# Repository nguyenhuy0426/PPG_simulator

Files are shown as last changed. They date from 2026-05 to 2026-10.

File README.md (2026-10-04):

# 🫀 PPG Signal Simulator — Raspberry Pi 4

**Dual-channel PPG research simulator with Raspberry Pi software, three KiCad 10 boards and a printable optical enclosure.**






**Group #2:** HuyNN, VyPT
**Institution:** Industrial University of Ho Chi Minh City (IUH) — Faculty of Electronic Technology
**Version:** 5.0.0 — waveform controls and timestamped recording

---

## 📋 Overview

The Raspberry Pi runtime synthesizes IR/RED signals at 100 Hz, interpolates them
for a nominal 500 Hz dual-MCP4725 output on ARM64, and acquires OPT101 signals separately.
`PPG_DAC_RATE_HZ` supports 100/200/500/1000 Hz; desktop default is 1000 Hz.
Pi GUI + BLE + A0 verification at 500 Hz completed 30 seconds without buffer
overruns or dropped samples. Optical waveform fidelity is still unverified.
The empirical SpO₂ mapping is configurable; a realistic plot does not establish
optical accuracy or compatibility with a particular pulse oximeter.

**Touch and sequence update (30 September 2026):** Numeric controls use sliders;
Settings and calibration include −/+ fine steps. **04 PPG morphology** offers
fitted Gaussian and an exploratory **LSM-GAN 30-second sequence**, a real training
reference, and a live **OPT101 RX** card (A0/A2). **A2 is disabled until its sensor is installed.**
Play/Stop uses the shared MCP4725 writer; clips stop at 30 seconds or when leaving
the page. Opening the page does not emit output. Classic Gaussian is preserved.

LSM keeps native 40 Hz timing and has no HR/notch conditioning. The existing v2
checkpoint has excessive beat variability relative to median validation data;
it is a development baseline, not a validated human-PPG replacement. IR/RED share
one shape with nominal scaling. See [architecture choice, measured sequence audit
and touch/output details](docs/ppg_touch_sequence_output_2026-09-30.md).
The [earlier morphology comparison](docs/ppg_morphology_selection_2026-09-28.md)
remains a historical exploratory result; test has already been viewed.

**RX beside TX & Bench Diagnostics (October 2026):**
- **Live A0/A2 RX card on every page:** Classic, Calibration, Recordings and PPG morphology each show a read-only RX card next to the TX plot (the earlier bottom dock, and the RX strip inside the Signal setup window, are removed). It displays the rolling 8-second window of raw ADC mV at up to 10 Hz refresh, with explicit status states (disabled, dry-run, stale, error, full-scale) and touch-optimized scrolling on 1024×600 screens ([docs/rx-monitor-2026-10-01.md](docs/rx-monitor-2026-10-01.md)).
- **Physical Sensor Diagnostic Protocol:** A bench test and signal conditioning plan is established for OPT101 / CJMCU-101 modules, covering internal 1 MΩ feedback verification, 3.3 V Grove Hat input limits, dark readings, stepped sine wave tests (1–10 Hz), and RC low-pass filtering at $f_c \approx 33.9\text{ Hz}$ ([docs/opt101-a0-diagnostic-2026-10-01.md](docs/opt101-a0-diagnostic-2026-10-01.md)).

| Live monitor | Waveform setup | 30-second sequence |
|---|---|---|
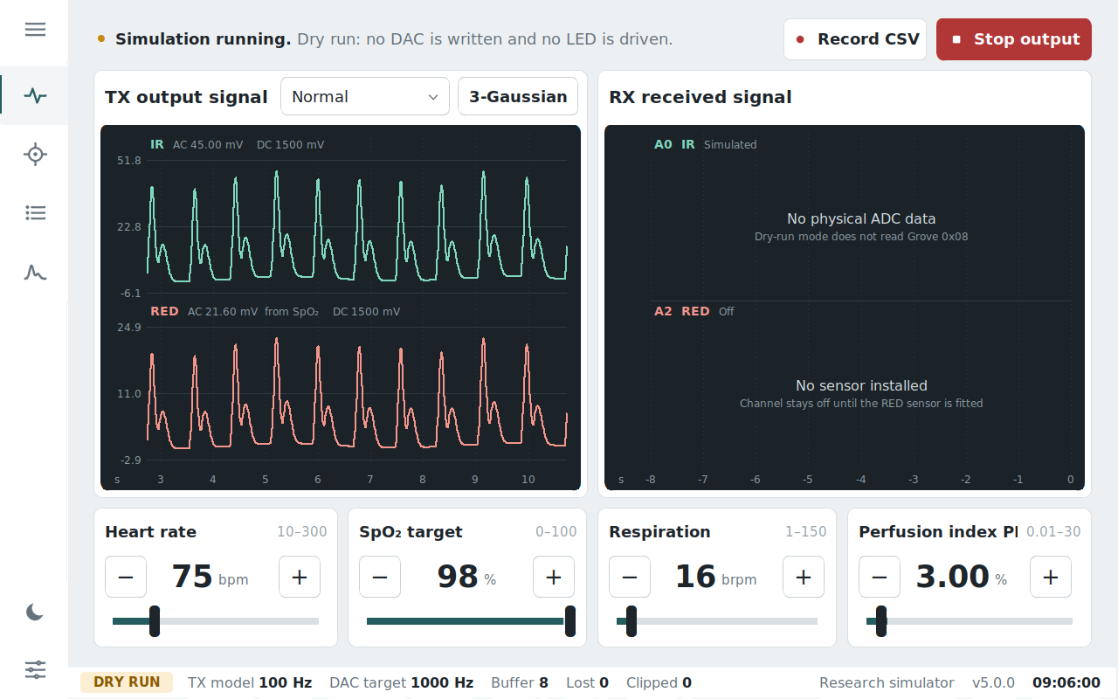
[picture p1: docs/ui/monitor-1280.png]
PPG monitor in dry-run mode
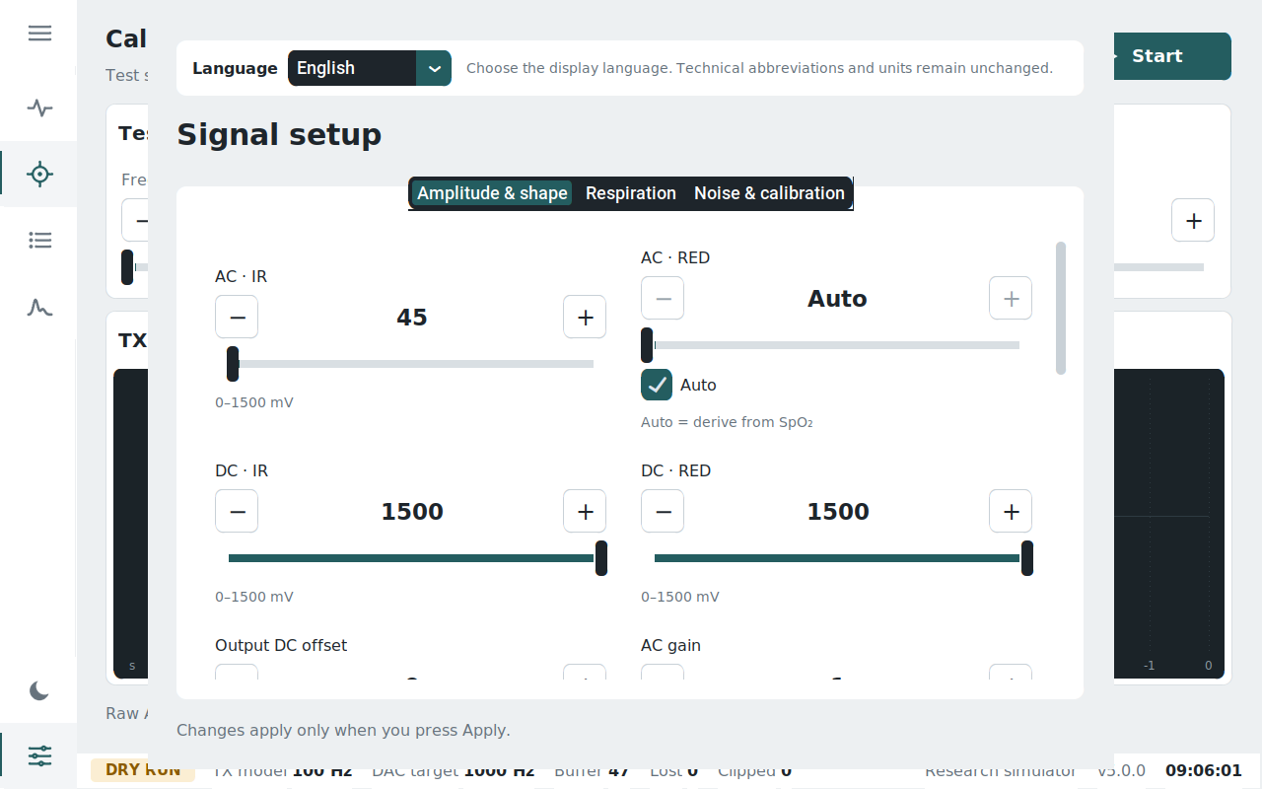
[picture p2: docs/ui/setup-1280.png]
Signal setup controls
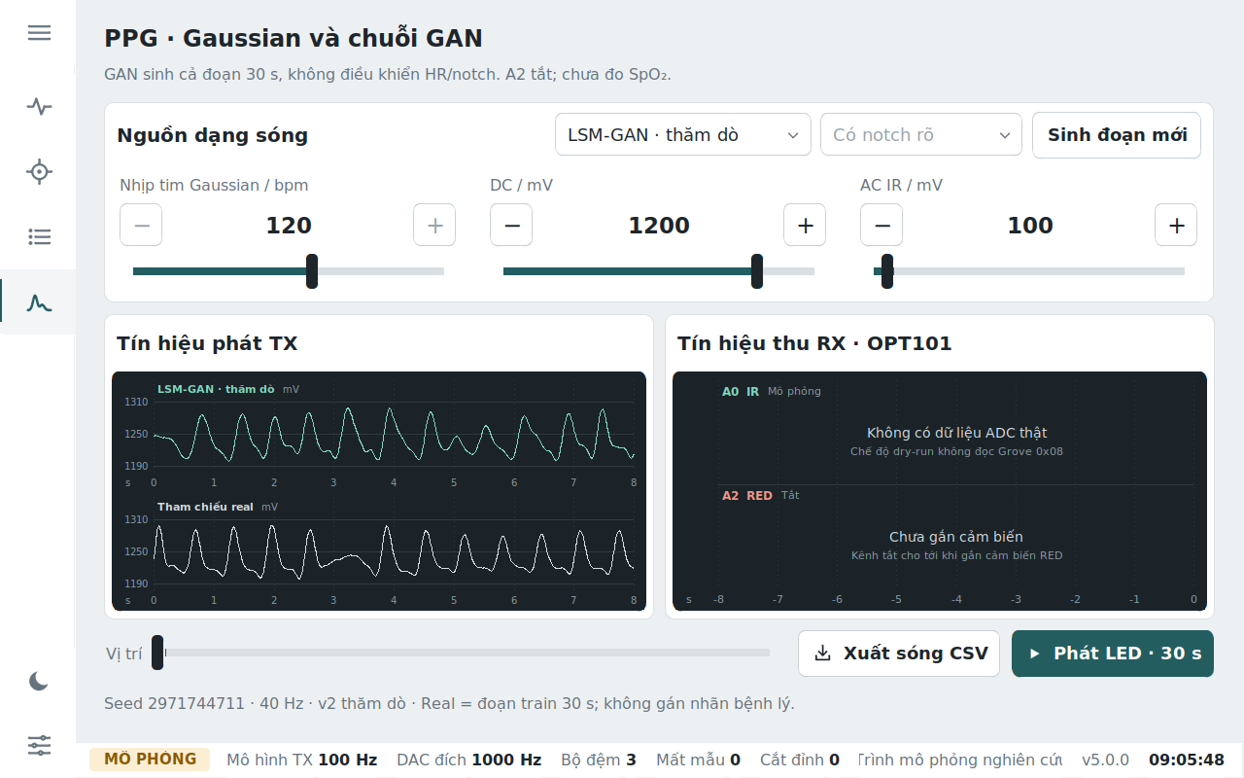
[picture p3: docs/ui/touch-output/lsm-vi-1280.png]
LSM-GAN sequence screen
|  |  |  |

### What's complete in v5

- Light controls, charcoal IR/RED plots, large setpoints and timestamp axes. The UI scales automatically from compact 7-inch 1024×600 panels through Full-HD/QHD desktop displays.
- HR 10–300 bpm; respiration 1–150 brpm; SpO₂ target 0–100%; PI convenience input 0.01–30%.
- Independent IR/RED AC and DC, AC/DC ownership, output offset, gain and polarity.
- PPG, sine, triangle and square waveforms; independent SP/DN/DP timing for each channel.
- Baseline, amplitude and frequency respiratory modulation, inhale/exhale ratio, per-channel variation and periodic apnea.
- Absolute-mV artefacts with optional seeds; configurable HR/amplitude, SpO₂/notch and beat-variability effects.
- Timestamped 100 Hz model-command CSV recording continues across pages; playback follows the recorded timestamps.
- Explicit Start/Stop for calibration; only the engine's DAC thread produces its sine output.
- Configuration round-trip, validation and atomic JSON save. Opening a page does not change signal parameters.
- English/Vietnamese UI; touch-sized controls; TX on the left and live OPT101 A0/A2 RX on the right of every page. A2 acquisition awaits an installed sensor.
- Collapsible left navigation rail (icons collapsed, labels overlay when expanded), light/dark theme saved in `config.json`, and a Classic page with TX and RX side by side. The status line reports *no MCP4725 at 0x60/0x61* instead of claiming LED output when the DACs do not answer.
- `scripts/deploy_and_run.sh` (run on the laptop): SSH check, `i2cdetect -y 1` report for 0x08/0x60/0x61, rsync to the Pi, restart the app on the Pi display, and a dry-run copy on the laptop. When the Ethernet link reports `NO-CARRIER`, use the Wi‑Fi address: `PI_HOST=user@<pi-wifi-ip> scripts/deploy_and_run.sh`, and stop any other running instance first so two apps do not share I2C/BLE.

See [the continuation and validation report](docs/phase_reports/V5_CONTINUATION_REPORT.md)
for scope, evidence, commercial-reference comparison and physical validation still needed.

### Neural waveform models

The current **04 PPG morphology** page keeps the original three-Gaussian
generator and offers the LSM-GAN sequence as an experimental model. The
cWGAN-GP checkpoint below is retained for research comparison; it is not the
current sequence source. Both neural models were trained from BIDMC 1.0.0 PPG
records using subject-separated train/validation/test groups. They do not learn
separate IR and RED optical channels.

| Model | What goes in → what comes out | Network idea | Current role |
|---|---|---|---|
| cWGAN-GP pilot | 32-value random latent vector + 7 measured morphology conditions → one 256-point, phase-normalized pulse | Dense layers followed by three linear-upsample/Conv1D stages; strided-convolution critic; Wasserstein loss with gradient penalty | Research artifact only; the pilot export contains G but not its trained critic. The app's older preview repeated this one pulse to form a longer trace. |
| LSM-GAN v2 | A random 1,200-point noise strip → 1,200 PPG samples, 30 s at 40 Hz | Generator has parallel Conv1D branches (kernels 5/21/61) and a spectral-matching objective; its discriminator is a CNN with two real/fake scores | Experimental long-sequence option in page 04; no HR/notch control. |

For LSM-GAN, training used 624 non-overlapping 30-second windows from 32
patients; validation and test each used 112 windows from 7 separate patients.
BIDMC's 125 Hz signals were resampled to 40 Hz, filtered at 0.9–5 Hz and
normalized per window. This is not raw, full-band PPG or a healthy-population
dataset. The model produces a normalized shape; the app maps that shape to
nominal IR/RED voltage levels, so it does not predict two independently learned
optical signals or calibrated SpO₂.

These experiments are **exploratory** because the test set had already been
viewed. cWGAN makes a single pulse while LSM-GAN makes a long sequence, so
their scores are not a fully like-for-like ranking. Selection considers the
pre-agreed spectrum similarity, autocorrelation and high-frequency energy;
loss and discriminator scores alone are not evidence of realistic PPG.
See the [detailed LSM/GAN report](docs/ppg_lsm_gan_report_2026-09-26.md),
[cWGAN and LSM integration audit](docs/ppg_neural_preview_report_2026-09-28.md)
and [current sequence and hardware validation](docs/ppg_touch_sequence_output_2026-09-30.md).

### Key Specifications

| Parameter | Value |
|---|---|
| Platform | Raspberry Pi 4 (Ubuntu 24.04/26.04 LTS, arm64)  |
| UI Library | CustomTkinter |
| DAC | MCP4725 (12-bit, I2C) × 2 — IR & Red channels |
| Model Rate | 100 Hz |
| DAC Rate | Pi: 500 Hz target; configurable; Linux/I²C timing requires measurement |
| Data Recording | 100 Hz model commands, timestamped CSV in `dataset/` |
| DAC Voltage Range | Configured 0–3.28 V (0 → 0, 3.28 V → 4095) |
| Live RX ADC Channels | A0 (IR) & A2 (Red) on Grove Base Hat (I2C 0x08) |

---

## 🛠️ Hardware Architecture

### Pin Mapping (Raspberry Pi 4, BCM numbering)

```
MCP4725 DACs (I2C Bus 1):
  GPIO2 (pin 3)   → I2C1_SDA
  GPIO3 (pin 5)   → I2C1_SCL
  Addresses: 0x60 (IR channel), 0x61 (Red channel)

Display:
  HDMI → Any screen (auto-detect resolution)
```

### Three KiCad 10 boards

The current CAD release has two alternative receiver boards and one LED
driver. Assemble **either** receiver for the optical channel pair; the V-cut
panel contains all three designs for fabrication, then separates into three
electrically independent boards.

| Board | Size | Main parts | Project |
|---|---:|---|---|
| OPT101 receiver | 70 × 20 mm | Two OPT101P in DIP-8 sockets; 2 mm Grove A2/RED and A0/IR headers; ADS1115 signal header; supply bypass and output RC | [Schematic, PCB and assembly notes](hardware/opt101_receiver_kicad/opt101_receiver/README.md) |
| BPW34 receiver | 70 × 20 mm | Two BPW34, two OPA333 TIAs, 1 MΩ/22 pF feedback, 2 mm Grove headers, ADS1115 signal/GND header | [Schematic, PCB and assembly notes](hardware/bpw34_receiver/README.md) |
| LED/IR driver | 70 × 40 mm | Two plug-in MCP4725 modules, socketed LM358, two 2N4401 current sinks, LED and 5 V headers | [Schematic, PCB and assembly notes](hardware/led_ir_driver/README.md) |

| OPT101 receiver | BPW34 receiver | LED/IR driver |
|---|---|---|
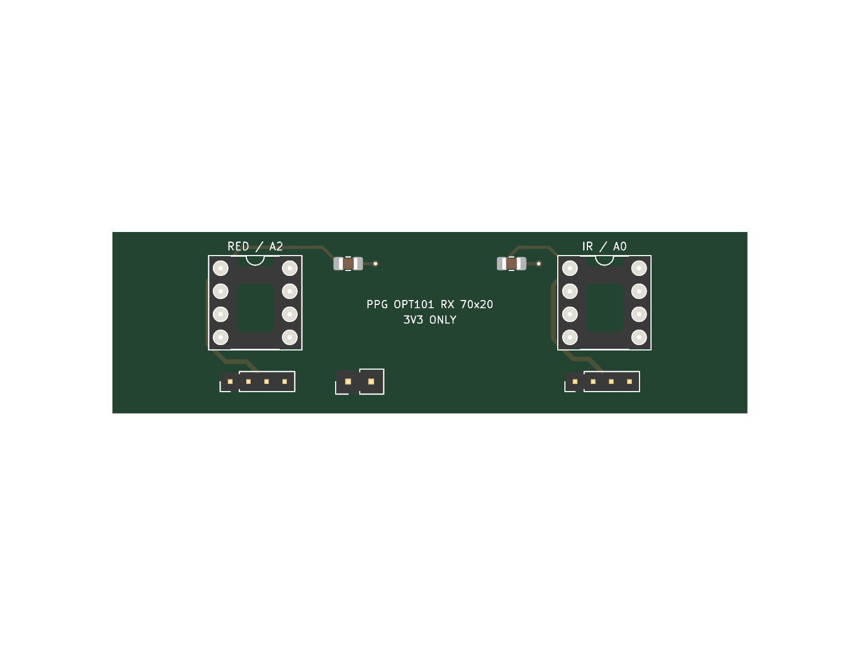
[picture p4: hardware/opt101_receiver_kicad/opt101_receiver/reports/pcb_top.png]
OPT101 receiver PCB
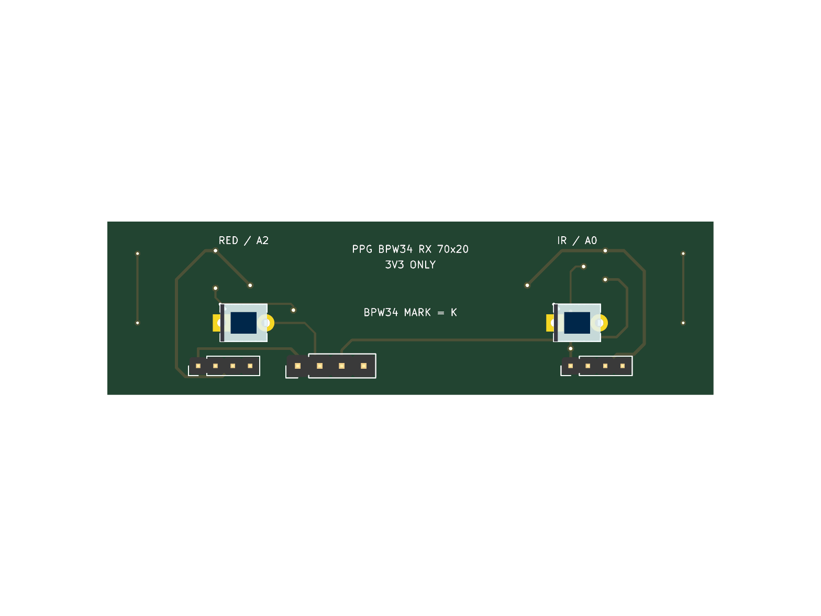
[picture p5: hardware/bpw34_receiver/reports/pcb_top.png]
BPW34 receiver PCB
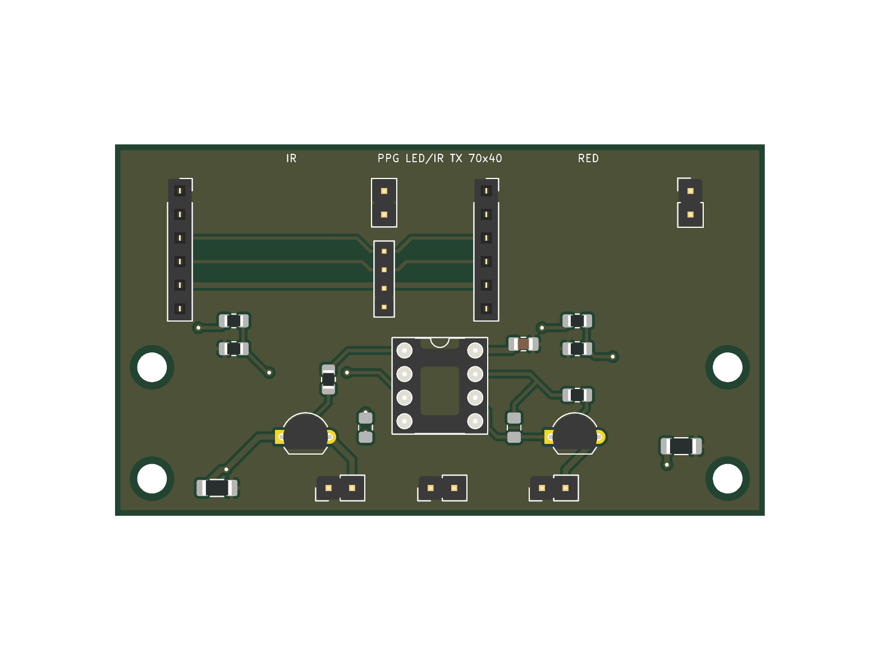
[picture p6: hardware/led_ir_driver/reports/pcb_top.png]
LED and IR driver PCB
|  |  |  |

The [70 × 80 mm V-cut panel](hardware/ppg_panel/README.md) marks two score lines
at 20 and 40 mm. Copper stays at least 1.5 mm from each line. Send the
[panel fabrication ZIP](hardware/PPG_3boards_VCUT_panel.zip) to a board house
that accepts three designs on one panel. Standalone packages are available for
[OPT101](hardware/PPG_OPT101_receiver.zip), [BPW34](hardware/PPG_BPW34_receiver.zip)
and the [driver](hardware/PPG_LED_IR_driver.zip). Confirm V-score capability and pricing with the board house;
separate the bare boards before soldering.

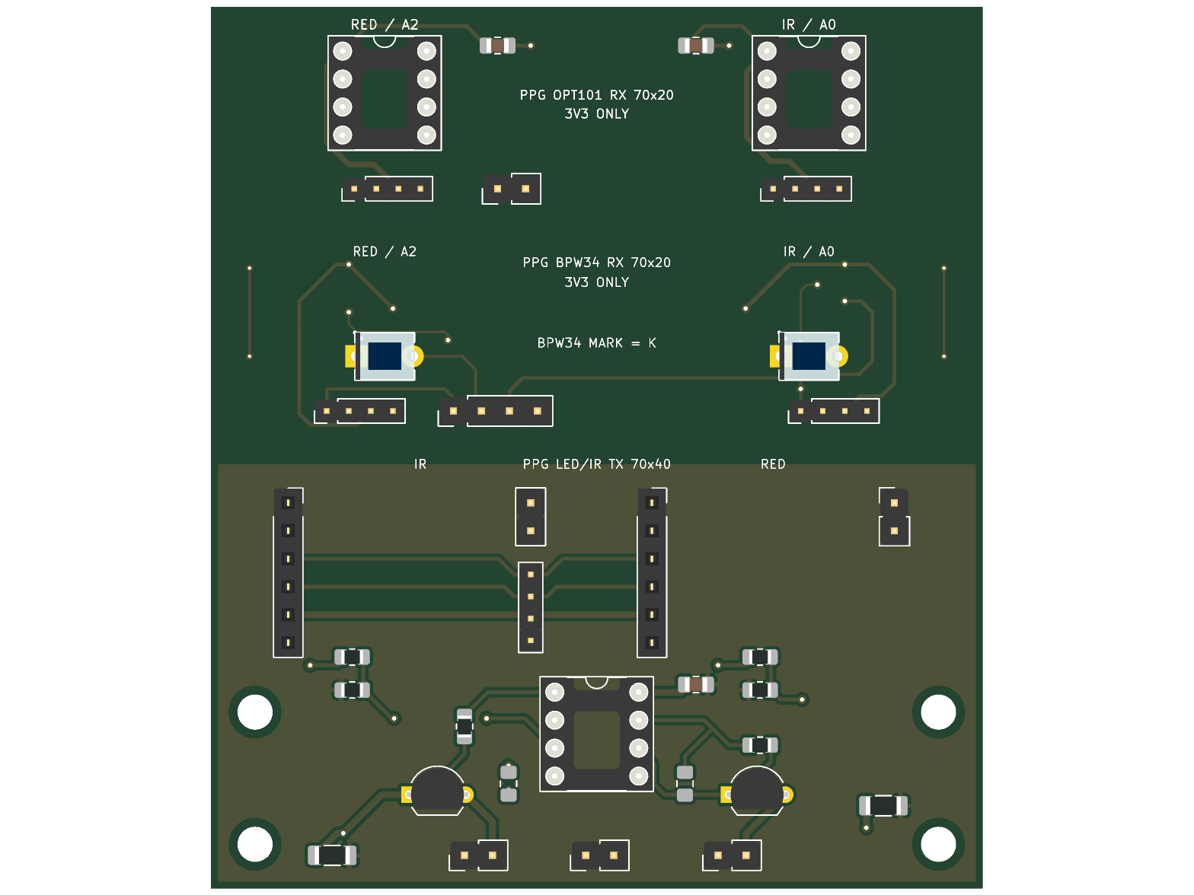
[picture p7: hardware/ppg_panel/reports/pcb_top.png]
Three-board V-cut fabrication panel

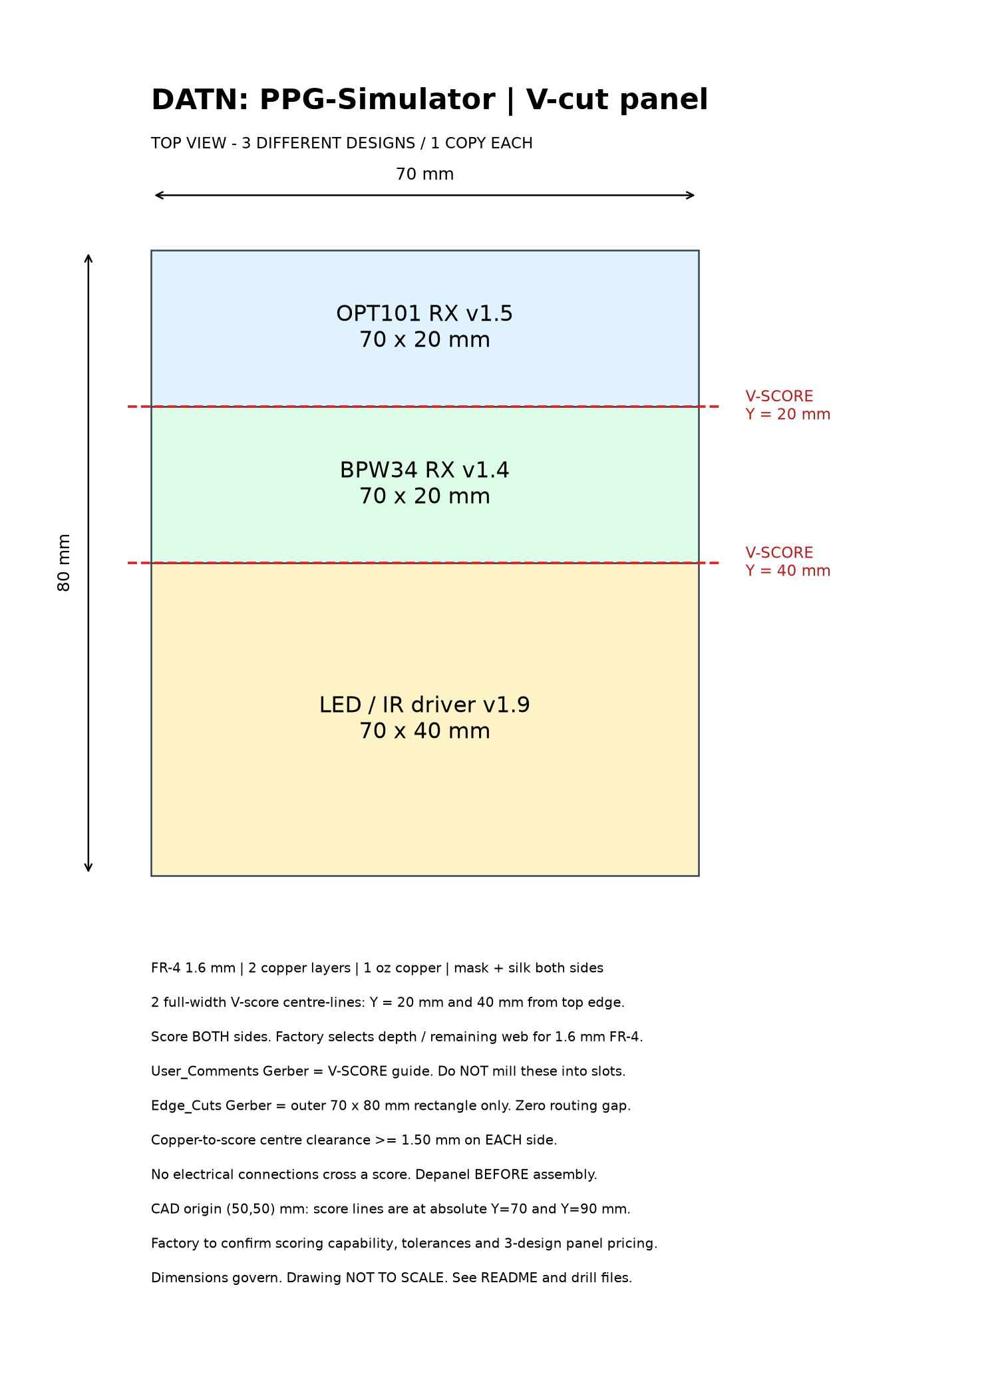
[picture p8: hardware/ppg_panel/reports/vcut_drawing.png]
V-cut positions and dimensions


#### PCB Routing Quality & Chamfering

All three PCB layouts and the fabrication panel have undergone automated geometric auditing and cleanup:
- **100% 45° Chamfered Corners:** Automated chamfering (`hardware/routing_45.py`) converts all right-angle bends into smooth $1.2\text{ mm}$ 45° diagonal transitions, preventing acid traps and impedance discontinuities while preserving clearance.
- **Copper Segment Cleanup:** `clean_segments()` resolves multi-node track junctions, deduplicates coincident traces, merges collinear segments, and eliminates non-functional copper stubs.
- **Detailed Wiring Guides:** Enhanced wiring guides ([BPW34 guide](hardware/bpw34_receiver/reports/wiring_guide.png), [Driver guide](hardware/led_ir_driver/reports/wiring_guide.png)) render net-colored tracks and explicitly mark interlayer vias with white circular glyphs to assist manual assembly, testing, and probe placement.
- **DRC Verification:** KiCad design rule checks confirm 0 DRC violations, 0 unrouted nets, and full compliance with 2-layer FR-4 $1.6\text{ mm}$ manufacturing constraints.

### Printable optical enclosure

The dark chamber has separate RED/IR lanes, a sliding LED carrier, replaceable
apertures, a labyrinth lid and cable passages. The parametric model and assembly
instructions are in [docs/system_3d](docs/system_3d/README.md). For a 180 mm
Bambu bed, use the [three-plate print package](docs/system_3d/out/print_bambu_180.zip)
for the original enclosure parts. The compact receiver PCBs use **separate H-shaped
supports**, with open space under the PCB for header cables: [OPT101 STL](docs/system_3d/out/print_bambu_180/14_ga_chu_U_OPT101_70x20.stl)
and [BPW34 STL](docs/system_3d/out/print_bambu_180/15_ga_chu_U_BPW34_70x20.stl).
The driver has its [70 × 40 mm adapter STL](docs/system_3d/out/print_bambu_180/16_ga_driver_70x40.stl).
Read the [mounting notes](docs/system_3d/out/print_bambu_180/README_PCB_MOUNTS.md)
before printing: the receiver support is 3.8 mm thick in a 4.3 mm nominal slot;
test-print one support and check fit in the actual enclosure.

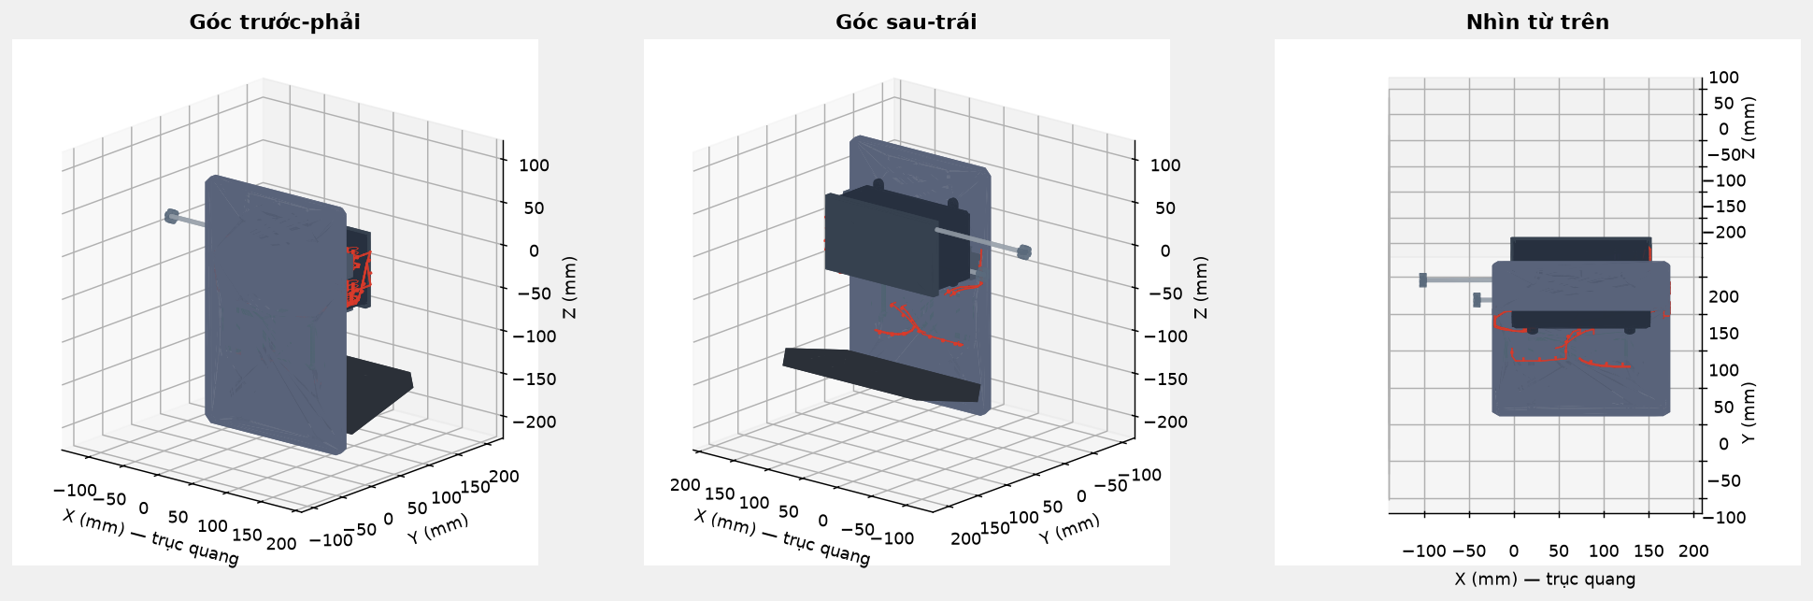
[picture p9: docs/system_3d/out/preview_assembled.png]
Assembled optical enclosure

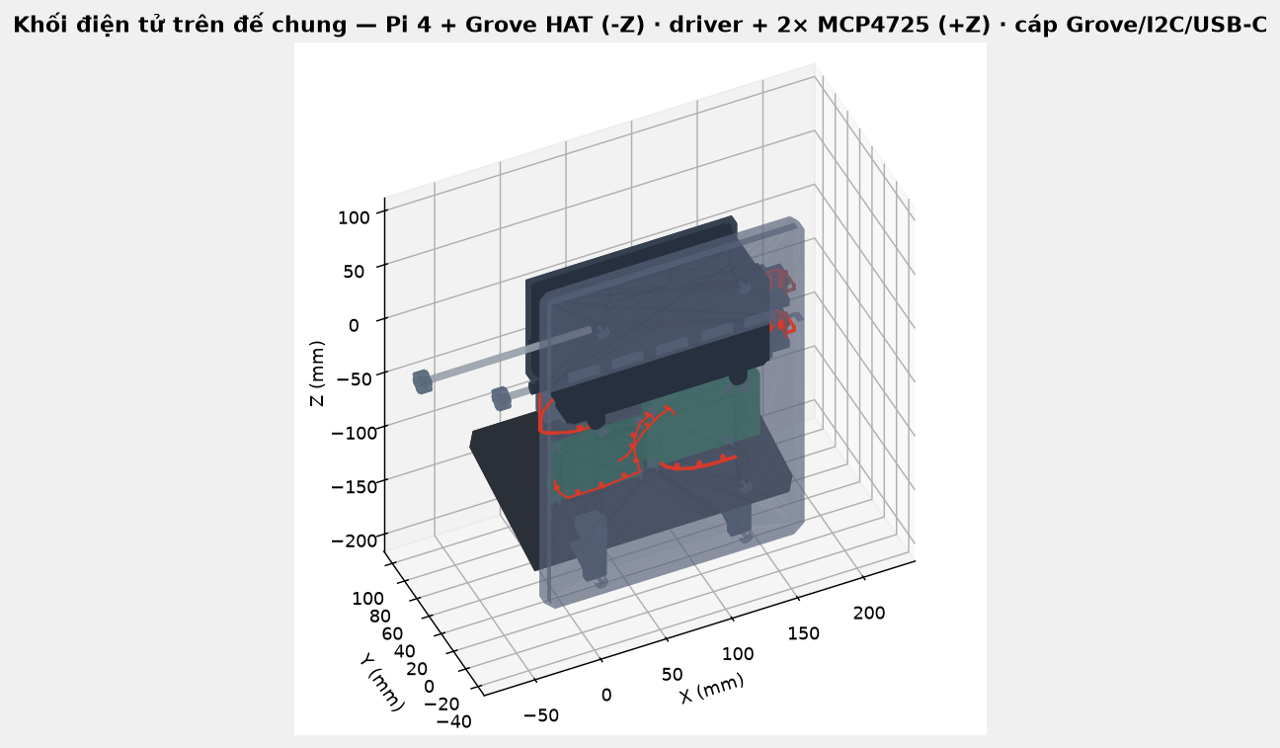
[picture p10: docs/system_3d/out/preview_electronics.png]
Electronics inside the model


KiCad ERC/DRC, schematic-to-PCB checks and nominal mechanical collision checks
are recorded in each hardware project's `reports/` and `mechanical/` folders.
They do not establish physical fit, analog noise, optical isolation or LED current.
Check module pin order, MCP4725 I²C addresses, supply voltage and fit on the
actual parts before powering the assembly.

> **The IR lane has no STLs of its own — this is deliberate, not a missing
> export.** The two optical lanes are mirror-symmetric about z = 0, so the
> `slide_shaft`, `led_carrier`, `push_rod`, `rod_knob`, `aperture_*` and `hood_*` parts are
> exported once under the `_red` name and printed twice (the `*_ir` copies exist
> in `model.json` for the viewer only). Print counts are in the STL table of the
> `docs/system_3d/` README.

---

## 💻 Software Architecture

### Folder Structure

```
PPG_simulator_raspi/
├── main.py                      # Application entry point
├── config.py                    # Constants, theme & styles (single source of truth for version)
├── config_store.py              # JSON configuration persistence & validation
├── core/
│   ├── signal_engine.py         # Signal generation thread & DAC output
│   ├── csv_logger.py            # Dataset recording logic
│   ├── tx_rx_logger.py          # Paired TX command & RX acquisition logger
│   ├── rate_scheduler.py        # Drift-free fixed-rate execution ticker
│   └── state_machine.py         # System operational state machine
├── hw/
│   ├── opt101_rx.py             # Grove Base Hat ADC reader (A0/A2 channels)
│   ├── dac_manager.py           # Dual MCP4725 I2C DAC controllers
│   ├── adc_reader.py            # Low-level ADC reading interface
│   └── button_handler.py        # Physical push-button interrupt handler
├── models/
│   ├── ppg_model.py             # PPG physiological synthesis model
│   ├── noise.py                 # Artefact generators (absolute-mV, band-limited)
│   ├── respiration.py           # Respiratory baseline/amplitude/RSA modulation
│   ├── waveform.py              # Pulse morphology (Gaussian, sine, square, triangle)
│   └── limits.py                # Parameter limits and boundary validation
├── led_driver/                  # Op-amp + BJT current-sink calculations & error budget
├── ui/
│   ├── ctk_app.py               # Main CustomTkinter UI shell & window manager
│   ├── rx_monitor.py            # Read-only A0/A2 RX lanes shown beside TX on every page
│   ├── trace_view.py            # High-performance trace plot widget
│   ├── touch_slider.py          # Touch-optimized slider with +/- step buttons
│   ├── advanced_controls.py     # Parameter validation & event dispatcher
│   ├── i18n.py                  # English and Vietnamese UI translations
│   ├── responsive.py            # Multi-resolution UI scaling (1024x600 to 4K)
│   └── frames/
│       ├── pathology_frame.py   # Classic PPG simulator & pathology controls
│       ├── calibration_frame.py # Sine wave DAC test & calibration
│       ├── advanced_frame.py    # Signal setup (AC/DC ownership, SpO2, artefacts)
│       ├── neural_frame.py      # LSM-GAN 30s sequence & morphology evaluation
│       └── playback_frame.py    # CSV recording browser & playback viewer
├── hardware/                    # KiCad 10 projects, V-cut panel & release ZIPs
├── docs/                        # Design documents, reports, and 3D STL models
│   ├── opt101-a0-diagnostic-2026-10-01.md # Bench test plan for physical sensor
│   ├── rx-monitor-2026-10-01.md           # Live RX view design notes & validation (dock era)
│   ├── ppg_touch_sequence_output_2026-09-30.md # Touch controls & GAN details
│   └── system_3d/               # 3D printable dark enclosure STLs & guide
└── dataset/                     # Recorded CSV dataset files
```

---

## 🔧 Installation & Setup

### 1. Prerequisites
- Raspberry Pi 4 with Ubuntu 24.04 or 26.04 LTS (aarch64)
- I2C enabled (`dtparam=i2c_arm=on` in `/boot/firmware/config.txt`; the setup
  script can add it after confirmation)
- Python 3.10+ and OS package `python3-tk`; install dependencies inside a venv.

For Ubuntu, use the repository setup script instead of installing into the
system Python:

```bash
./scripts/setup_rpi_ubuntu.sh --enable-i2c
```

For a laptop-to-Pi Ethernet cable, source transfer, repeatable `ping`/`ssh`
commands, and remote debugging, follow
[docs/setup/RASPBERRY_PI_4_UBUNTU_26_04_SSH.md](docs/setup/RASPBERRY_PI_4_UBUNTU_26_04_SSH.md).

### 2. Laptop setup, run and tests

```bash
python3 -m venv .venv
.venv/bin/python -m pip install --upgrade -r requirements/test.txt
.venv/bin/python main.py --dry-run
PPG_DRY_RUN=1 .venv/bin/python -m pytest -q
```

On the configured Raspberry Pi, use `.venv/bin/python main.py` for hardware mode.
Virtual environments are deliberately excluded from Git; recreate one on each
machine because wheels and interpreter paths are architecture-specific.

GUI interaction and screenshot check (requires a real display or Xvfb):

```bash
.venv/bin/python scripts/smoke_ui.py --output docs/ui
```

Install the PPG Simulator icon in the Raspberry Pi application dashboard and
place a trusted shortcut on the desktop:

```bash
./scripts/install_desktop_launcher.sh
```

The launcher uses this checkout's `.venv`, starts the normal GUI with BLE,
prevents duplicate instances and writes startup logs to
`~/.local/state/ppg-simulator/launcher.log`.

The laptop environment verifier also audits Git hygiene and rejects committed
virtual environments, bytecode and generated package caches.

### 3. BLE remote control (Android app)

The simulator can be driven from the Android app (`com.medical.simulator`)
over BLE GATT: `pip install -r requirements/ble.txt`, then run with `--ble`
(GUI) or `--ble-only` (headless). The phone advertises-pairs as central, sends
JSON setpoint commands (HR/SpO₂/RR/PI/noise/condition plus AC/DC amplitude
0–1500 mV per channel) and receives the 50 Hz waveform plus a 5 Hz status
snapshot with bidirectional sync. Full contract: `docs/ble_protocol.md`.

```bash
PPG_DRY_RUN=1 .venv/bin/python main.py --dry-run --ble        # GUI + BLE
PPG_DRY_RUN=1 .venv/bin/python main.py --dry-run --ble-only   # headless
```

---

## Operation

**Monitor:** adjust HR, SpO₂ target, respiration and PI with sliders, or type a
value and press Enter. Run starts TX; Stop parks both DAC command values at zero.
Record CSV starts capture; Save recording closes the file into `dataset/data_N.csv`.
Closing the app saves an active recording. The plotted signal is generated TX,
not an optical measurement. The right-hand numbers are setpoints.

**Signal setup:** each tab applies only when its Apply button is pressed.
Blank RED AC derives it from SpO₂. Explicit RED AC disconnects that amplitude
from the SpO₂ target and the monitor reports this. Lock AC holds AC while a PI
change moves IR DC; Lock DC lets PI move AC; both locks make PI read-only.
Feature times are quoted at 60 bpm and scale with cycle duration.

For a repeatable nominal waveform, disable respiratory modulation and all three
physiological dynamics switches on the Respiration tab. Otherwise modulation,
HR coupling and beat variability deliberately change the instantaneous AC/HR.

**Calibration & Sine Generator:** enter sine frequency (1–10 Hz) and peak output (100–3280 mV),
then Start calibration. Opening the page alone does not start output. Leaving the
page stops an active calibration. Sine calibration drives both MCP4725 DAC channels simultaneously.

**Live RX card:** every page shows an RX card to the right of its TX plot
(the Signal setup window has none). The receiver samples the Grove Base Hat ADC at 100 Hz and refreshes the UI at up to 10 Hz,
plotting an 8-second rolling window for A0 (IR) and A2 (Red). Sensor readings display raw
millivolts alongside real-time connection status (`LIVE`, `STALE`, `DRY RUN`, `DISABLED`, or `FULL SCALE`).
Dry-run mode and unplugged sensors explicitly show disconnected states without fabricating data.

**Neural Sequence & Morphology Evaluation:** the **04 PPG morphology** page allows selecting
between the standard three-Gaussian pulse synthesis and an experimental 30-second LSM-GAN
continuous pulse sequence. Clips automatically stop at 30 seconds or upon navigating away.
Opening the screen does not activate DAC output without an explicit Play action.
The TX card stacks the generated lane over the real reference lane; the RX card
on the right shows A0/A2 from the receiver.

**Recordings:** review saved TX command CSVs without driving hardware. The session
list is a drawer that folds to one icon and closes after a recording is picked.
Recorded TX sits on the left and the live RX card on the right; that RX is the ADC
reading at viewing time, not data stored in the recording. New files
contain `Time_s` and `Source`; the first seven columns retain the legacy schema.
Legacy files without timestamps explicitly assume 50 Hz for screen playback.
CSV output is a model command record, not proof that a DAC wrote every sample.

**Bench Diagnostics & Optical Validation:** for physical sensor testing with the OPT101 / CJMCU-101 module,
follow the testing protocol in [docs/opt101-a0-diagnostic-2026-10-01.md](docs/opt101-a0-diagnostic-2026-10-01.md):
1. Verify module pinout (ensure 1 MΩ internal feedback loop between pins 4 & 5; do not leave floating).
2. Measure baseline dark voltage under complete optical enclosure sealing.
3. Perform stepped sine excitation (1, 2, 5, 10 Hz) via DAC to measure sensor linearity, phase shift, and harmonic distortion.
4. If high-frequency ripple or ADC noise is present, insert an anti-aliasing RC filter ($R = 4.7\text{ k}\Omega$, $C = 1\ \mu\text{F}$, $f_c \approx 33.9\text{ Hz}$) between the OPT101 OUT pin and Grove A0 input. Keep Grove signals strictly $\le 3.3\text{ V}$.

| Calibration and RX status | Recording review |
|---|---|
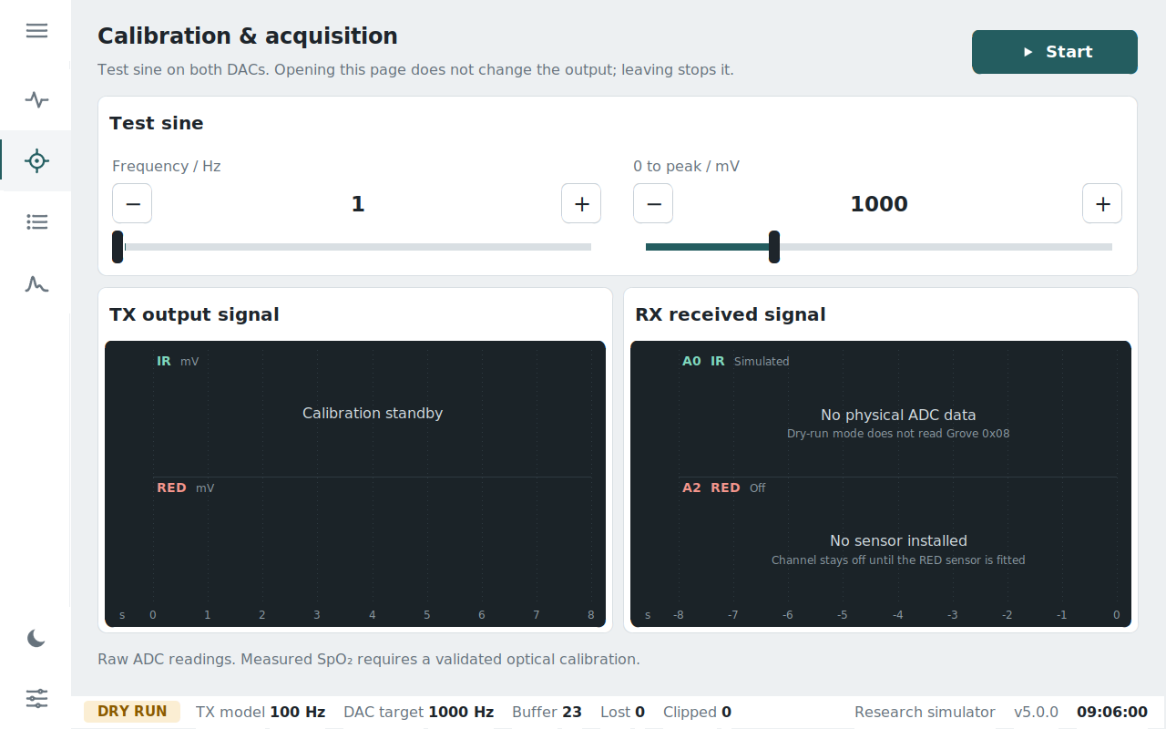
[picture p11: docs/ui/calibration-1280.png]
Calibration screen
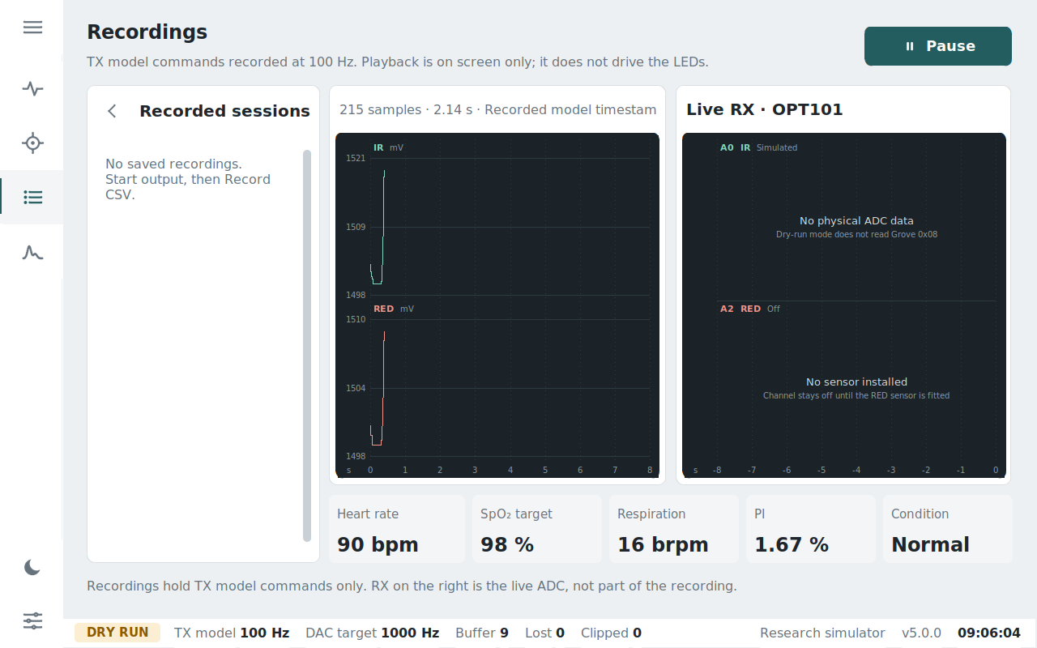
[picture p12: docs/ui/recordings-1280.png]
Saved waveform playback screen
|  |  |

## Signal relationships and limits

`PI = AC_IR / DC_IR × 100`; at DC=1500 mV, PI=3% gives nominal AC=45 mV.
RED is derived with the full ratio-of-ratios:

`R = max(0, (A − SpO₂_target) / B)`

`AC_RED = R × AC_IR × DC_RED / DC_IR`

The defaults A=110 and B=25 are an empirical example, not universal optical
calibration. The former R clamp of 0.4–1.6 has been removed so low SpO₂ targets
change the generated ratio. A negative requested R cannot be synthesized; the
monitor reports it. Unequal respiration depth and manually pinned RED AC can
change the instantaneous ratio from the nominal target.

PPG uses a normalized three-Gaussian shape. Respiratory depth defaults to 4% of
AC per channel, with baseline/amplitude/RSA modulation individually selectable.
Apnea suppresses respiratory modulation while cardiac pulses continue.

Direct AC entry spans 0–1500 mV and DC entry 0–1500 mV, matching the Android
app. PI-driven AC stays inside the direct AC range at these limits; output
offset spans 0–2000 mV with DC+offset≤3000 mV. Gain,
noise and modulation can still exceed DAC headroom: the output clamps to the
configured rails and the clipping counter reports it. A clipped waveform does
not meet the requested amplitude or ratio.

50/60 Hz mains noise is rejected by the 100 Hz synthesis model; 10× interpolation
does not create additional bandwidth. Likewise, the MCP4725 code step is about
0.80 mV at 3.28 V: software entry resolution is finer than physical DAC resolution.

The LED-driver topology in the supplied drawing is DAC → op-amp → NPN current
sink with emitter feedback through R_sense. The 3D preview defaults to this direct
command path, and offers the older 10k/10k divider hypothesis separately. Its
`I ≈ Vcmd/R` readout is an ideal estimate; current, compliance and optical response
must be measured on the actual assembly. No wiring, transistor or resistor is
changed by this software update.

## 👨‍💻 Authors

**HuyNN** — Hardware design, embedded firmware  
**VyPT** — Software design, UI/UX

**Institution:** Industrial University of Ho Chi Minh City (IUH)

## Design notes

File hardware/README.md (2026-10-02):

# Bộ PCB PPG — bản thu gọn và panel V-cut

**Gói gửi nhà in: `PPG_3boards_VCUT_panel.zip`.** Giải nén và đọc `SEND_TO_FAB.md` trước khi sản xuất.

Panel 70 × 80 mm chứa OPT101 70 × 20 mm, BPW34 70 × 20 mm và driver 70 × 40 mm. Hai đường V-score toàn chiều ngang ở 20/40 mm tính từ cạnh trên. Đồng cách tâm đường cắt ít nhất 1,5 mm mỗi phía; ba thiết kế không nối điện với nhau. Báo nhà in đây là **3 thiết kế khác nhau trên một panel** và xác nhận quy trình V-score.

- `ppg_panel/`: PCB panel, Gerber/drill, bản vẽ V-cut, kết quả kiểm tra và báo cáo điện.
- `opt101_receiver_kicad/opt101_receiver/`, `bpw34_receiver/`, `led_ir_driver/`: schematic/PCB nguồn và gá mới.
- Ba file ZIP board lẻ giữ cùng phiên bản mới nhất để xem/chỉnh hoặc in riêng; không trộn Gerber của chúng vào đơn hàng panel.

Đã kiểm tra ERC/DRC và parity ba nguồn; panel đối chiếu net/pad/track và lỗ/V-cut. Kết quả CAD không thay cho đo điện, nhiễu, ổn định vòng driver và thử lắp module thực. Xem `ppg_panel/ELECTRICAL_REVIEW.md`.

## Layout 45°

Ba board và panel đã vát góc rẽ dây 45°. Xem [đánh giá bố trí hai mặt và V-score](ppg_panel/LAYOUT_REVIEW.md).

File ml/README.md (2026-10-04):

# PPG cWGAN-GP pilot

Run v1 completed on Kaggle T4. **Not approved for deployment**: notch recall
was 2/103 (1.94%) on the evaluated test subset and boundary ripples remain.
See the [Vietnamese results report](../docs/ppg_gan_report_2026-09-26.md).

The additional [LSM-GAN experiment](kaggle_lsm/README.md) uses 30-second
40 Hz strips, trains/exports both G and D, and includes paper-objective,
corrected author-code-objective and no-spectral ablation arms. It is separate
from the conditional single-pulse interface; see the
[LSM report](../docs/ppg_lsm_gan_report_2026-09-26.md).

The follow-up [conditional architecture sweep](kaggle_arch/README.md) compares
five G/D configurations over three seeds. TCN-FiLM with a projection critic won
by validation and is the current research candidate; see the
[architecture report](../docs/ppg_architecture_sweep_report_2026-09-26.md).
It has not replaced the live generator or Gaussian fallback.

The training pipeline remains **offline research**, not a replacement for the
live PPG engine or an independently learned IR/Red model. The current **04 PPG
morphology** page retains the original Gaussian generator and supports the
experimental LSM-GAN long sequence. cWGAN-GP and TCN-FiLM are research artifacts
for historical comparisons, not selectable modes in the current page. Explicit
Play/Stop controls can send the selected waveform through the shared DAC path;
opening the page or generating a preview alone does not emit output. PyTorch is
loaded only when neural generation is requested. See the
[model overview in the main README](../README.md#neural-waveform-models),
[verified cWGAN/LSM audit](../docs/ppg_neural_preview_report_2026-09-28.md) and
[current sequence and hardware validation](../docs/ppg_touch_sequence_output_2026-09-30.md).

The [round 2 report](../docs/ppg_round2_report_2026-09-28.md) records the
historical multi-model UI, independent validation metrics, a 240-pulse
human-review page, and a gated three-arm fine-tuning pipeline. It is not a
description of the current simplified page. Only the two-step pipeline smoke
has run; human-reviewed fine-tuning and an unseen external cohort remain pending.

The [Gaussian fit](../docs/ppg_gaussian_fit_2026-09-28.md) tunes the existing
three-Gaussian formula on train data and evaluates all validation pulses.
`ml.fit_gaussian` reproduces the fit; `assets/gaussian/profiles.json` supplies
stdlib-only fitted previews alongside the unchanged original Gaussian.

## Reproduce

From the repository root (an isolated Python environment is recommended):

```bash
uv venv .venv-ml
uv pip install --python .venv-ml/bin/python -r requirements/ml.txt
.venv-ml/bin/python -m pytest tests/test_ml_ppg.py -q
.venv-ml/bin/python ml/kaggle/train_ppg.py --prepare-only --output ml/runs/prepared
.venv-ml/bin/python ml/kaggle/train_ppg.py --steps 1500 --output ml/runs/pilot-local
```

The local command can run on CPU; Kaggle refuses to train without a GPU. The
verified public MAT file can be cached at `dataset/bidmc/bidmc_data.mat`.
Otherwise the script downloads it from PhysioNet, then checks SHA-256. Use a
new output directory for each experiment. Keep dataset and run artifacts out
of Git. Python 3.11/3.12 is preferable to 3.14 for TorchScript compatibility.

Kaggle CLI, after authenticating locally (never put credentials in this repo):

```bash
uv tool run --from kaggle kaggle quota
uv tool run --from kaggle kaggle kernels push -p ml/kaggle --timeout 1800 --accelerator NvidiaTeslaT4
uv tool run --from kaggle kaggle kernels status charlesday2612/ppg-cwgan-gp-bidmc-pilot
uv tool run --from kaggle kaggle kernels logs charlesday2612/ppg-cwgan-gp-bidmc-pilot
uv tool run --from kaggle kaggle kernels output charlesday2612/ppg-cwgan-gp-bidmc-pilot -p ml/runs/kaggle-v1
.venv-ml/bin/python -m ml.evaluate_run ml/runs/kaggle-v1/ppg_run
```

Metadata makes the kernel private. Only the standalone training script is
uploaded; project configuration, PCB files and secrets are not inputs. The
timeout includes environment startup, downloads, preprocessing and training.
GPU usage consumes the account's Kaggle quota.

## Data and morphology contract

[BIDMC PPG and Respiration Dataset 1.0.0](https://physionet.org/content/bidmc/1.0.0/),
Pimentel et al., *Toward a Robust Estimation of Respiratory Rate From Pulse
Oximeters*, IEEE TBME 2017, DOI:10.1109/TBME.2016.2613126. License: Open Data
Commons Attribution 1.0. It provides critical-care PPG, not paired raw red and
infrared optical waveforms or manually labelled dicrotic notches. Retain this
attribution with derived data and models.

- Input sampling rate comes from each record's `ppg.fs` (125 Hz here).
- Group by **original MIMIC patient ID**, not recording number or individual
  beat. Multiple BIDMC recordings can belong to one patient. Seed 42 assigns
  70/15/15% of unique patients to train/validation/test (rounded down).
- NeuroKit2 Elgendi cleaning/peak detection locates systolic beats. A separate
  fourth-order, zero-phase 12 Hz lowpass trace supplies morphology, followed
  by foot-to-foot segmentation, linear baseline subtraction, peak scaling
  and PCHIP interpolation to 256 phase points, including both endpoints.
- Engineering inclusion: HR 40–180 BPM, SP phase 0.05–0.55; reject flat traces,
  baseline undershoot worse than 5% of pulse height and more than three large
  peaks. Lesser negative baseline residuals are clipped before interpolation.
  These rules are **not clinical normal ranges** and are not a complete motion
  artifact or arrhythmia screen. Filtering and segmentation can alter notches.
- SP = global pulse maximum. DP = first later local peak with at least 2% SP
  prominence, more than 6% cycle after SP and before phase 0.90. DN = local
  minimum between them. Peak separation is at least 3% cycle. Inflections
  without a resolvable second peak receive `has_notch=0`; they are not labelled
  unhealthy. Pseudo-labels still need visual/manual review.
- Condition: `[HR/200, SP_phase, DN_phase, DP_phase, DN/SP, DP/SP, has_notch]`.
  Missing DN/DP fields are zero, with a separate presence flag. These are
  measured extrema, **not Gaussian component centers or `dicrotic_depth`**.
- No age, disease, SpO2 or sensor-site conditioning is learned in this pilot.
  Conditions must stay in training support; independent min/max bounds do not
  establish that an arbitrary combination is feasible.

## Training and evaluation

Lightweight 1D conditional generator: 32-dimensional latent vector, 7
conditions, dense layers followed by three linear upsampling/convolution
stages. Output is one nonnegative unit-height pulse with zero endpoints.
Critic has strided convolutions and no batch normalization. There are 284,321
generator parameters. This is a project-specific architecture, not a claim
that one published PPG model has been reproduced.

Wasserstein objective with gradient penalty 10, five critic updates per
generator update, Adam `lr=1e-4, betas=(0,0.9)`, batch 64. A weak differentiable
landmark penalty (weight 10) encourages condition adherence; it is an
experimental addition, not a physiological theorem. There is no paired
waveform L1 loss. Reference: [Gulrajani et al. (2017)](https://arxiv.org/abs/1704.00028).

Checkpoint selection uses a fixed validation subset and condition error only;
the final selected checkpoint is evaluated once on 512 held-out test beats.
That selection score alone is insufficient to establish realistic shape.
The two-step local smoke test verifies execution, not model quality.

Comparators:

1. **Current default Gaussian**: the corrected project's default morphology,
   sampled on the same phase grid. A regression test checks equality. It is
   neither condition-matched nor fitted, so beating it is not evidence of
   beating an optimized Gaussian model or the user's saved config.
2. **Real replay**: nearest condition vector from training patients only.
   This is a strong practical baseline; it intentionally reuses real pulses.
3. **Held-out real**: reference morphology; it is not used as the replay bank.

Report SP/DN/DP errors, notch presence accuracy, SP distribution distance,
pointwise variation, fixed-condition variation, roughness and distance to a
seeded 2,048-pulse training subset. DN/DP error is conditional on both target
and output having a detected notch, so it must be read alongside recall and
the matched count. Nearest-neighbor distance to a subset is only a limited
memorization diagnostic, not a privacy guarantee. Aggregate beat metrics
weight patients unequally; patient-level confidence intervals, repeat seeds,
optimized Gaussian fitting and external-cohort tests remain future validation.

Outputs include `manifest.json`, `prepared.npz`, `history.json`,
`generator_best.pt`, `generator_cpu.ts`, `metrics.json`, `test_samples.npz`,
`comparison.png`, and IR/Red CSV examples. `manifest.json` retains source Fs,
patient splits, per-record rejection counts, condition schema and train bounds.
`metrics.json` records software versions, device, seed and training-code hash.

## Fs, IR/RED and Raspberry Pi

`256` is a phase-grid length, **not 256 Hz**. For clock `Fs` and heart rate `HR`:

```text
t[n] = n/Fs
phase[n] = (t[n] * HR/60) mod 1
p[n] = interpolate(G(z, condition), phase[n])
samples_per_cycle = Fs * 60/HR
IR[n]  = DC_IR  + polarity * AC_IR  * p[n]
RED[n] = DC_RED + polarity * AC_RED * p[n]
R = max(0, (A - SpO2)/B)
AC_RED = R * AC_IR * DC_RED/DC_IR
```

Example: `HR=75`, `Fs=100` gives 80 samples/beat; `Fs=1000` gives 800.
With A=110, B=25, SpO2=98, equal DC=1.5 V, and AC_IR=45 mV, R=0.48 and
AC_RED=21.6 mV. These coefficients are the simulator's assumed calibration,
not a universal physiological law. DC means the existing pedestal parameter,
not the time-average voltage. Pinning AC_RED or using actual optical hardware
requires preserving/rechecking the existing calibration policy.

The CSV renderer exports exact configured timestamps and rejects voltage rail
violations. It does not measure a physical clock, validate optical SpO2, add
respiration/noise, or anti-alias for arbitrary low output Fs. Exporting 1000 Hz
does not recover information absent from the 125 Hz source. Evaluate bandwidth
and filtering before changing the production sample-rate path.

Deployment direction: load the CPU artifact on Pi, generate/cache a pulse
outside the DAC timing loop, then let the existing phase/AC/DC/polarity pipeline
render it. Current model rate is 100 Hz and timer configuration is 1000 Hz;
their physical accuracy has not been measured in this work. Keep the Gaussian
engine as fallback. Do not install GPU training dependencies in the live app.
Benchmark on the actual Pi model, OS and architecture before choosing a runtime;
TorchScript export alone is not proof of Pi compatibility or real-time safety.
No default engine switch, UI/BLE contract change, optical output or Pi
deployment is performed by this pipeline.

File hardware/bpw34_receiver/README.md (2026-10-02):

> Gá mới: thanh chữ U không bắt vít, hai biến thể riêng theo receiver. Xem `mechanical/README.md`.

# Dual BPW34 receiver for DATN: PPG-Simulator

This is a complete KiCad 10 project for a 70 x 20 mm, two-channel photodiode receiver that can replace the dual-OPT101 board mechanically. The optical centres remain 38.5 mm apart. The new screwless U support shares the enclosure slot; PCB mounting holes are removed.

## Electrical design

Each channel is independent and contains one BPW34, one OPA333 transimpedance amplifier, a 1 Mohm feedback resistor, and a 22 pF C0G/NP0 feedback capacitor. A 100k/10k divider creates a filtered 0.30 V reference from the 3.3 V Grove supply. Light-induced reverse current therefore raises the output:

`VOUT approximately 0.30 V + IPD x 1 Mohm`

R3/R4 = 1 kohm and C7/C8 = 1 uF X7R 16 V form an output low-pass filter (159 Hz nominal). The capacitor connects after the resistor to its channel ground. Attenuation at 20 Hz is approximately 0.8%; this is not a 50 Hz notch filter. C1/C2 are C0G/NP0 because their value sets TIA stability; C3-C6 are non-polar 100 nF X7R ceramic capacitors. No electrolytic capacitor is required.

The preferred amplifier is `OPA333AIDBVR` in SOT-23-5. The lower-cost `MCP6001T-I/OT` has the same pinout and footprint, but higher offset and drift. The board does not support LM358 because its input/output headroom is a poor match for a 3.3 V photodiode TIA.

The schematic now draws R1/C1 and R2/C2 as two visible parallel feedback branches between each BPW34 cathode (SUM) and the OPA333 output (FB). A supply arrow marks each channel's `3V3_RED` or `3V3_IR` net; a ground symbol marks `GND_RED` or `GND_IR`. The two channel grounds remain separate. The former diamond-shaped `PWR_FLAG` symbols have been removed; the Grove connector power pins are declared as the external source for KiCad ERC.

## Connectors

| Connector | Pin 1 | Pin 2 | Pin 3 | Pin 4 |
|---|---|---|---|---|
| J1, Grove A2 | OUT_RED | NC | 3V3_RED | GND_RED |
| J2, Grove A0 | OUT_IR | NC | 3V3_IR | GND_IR |
| J3, ADS1115 | OUT_RED | GND_RED | OUT_IR | GND_IR |

J1 and J2 are 1x4 male headers with 2.00 mm pitch. J3 is a 1x4 male header with 2.54 mm pitch. J3 intentionally carries no supply; power the ADS1115 normally and connect both J3 ground pins to its GND. The channel grounds remain separate on this PCB and meet at the HAT or ADS1115.

The Grove Base Hat must be configured for 3.3 V. Pin 2 of each Grove connector is deliberately unused.

## BPW34 polarity

Pad 1 is the cathode (`K`) and is square. Pad 2 is the anode (`A`) and is round. Match the BPW34 cathode marking to `K`; reversing the diode changes the bias and output polarity.

## Manufacturing and assembly

- 2 layers, FR-4, 1.6 mm, 70 x 20 mm.
- Solder D1/D2 and the three headers on the front.
- Solder U1/U2 and all 0805 parts on the rear.
- The rear components are arranged as two channel blocks: the feedback pair is
  in the upper row, the OPA333 and 1 kohm output path are in the middle, and
  the VREF divider is in the outer column. All reference designators read
  horizontally from the rear.
- The high-impedance `SUM_RED`, `SUM_IR`, `FB_RED`, and `FB_IR` routes remain
  on B.Cu and are kept local to their channel. The long supply/output runs use
  the opposite layer where needed, so they do not cut through the TIA loops.
- Every routed copper segment on F.Cu and B.Cu is horizontal, vertical or 45 degrees; the
  layout intentionally contains no diagonal track segments.
- Receiver mounting holes are removed; no copper crosses a drilled mounting opening.
- Both sides carry pin markings. On the rear, every J1/J2/J3 pad is labelled
  individually with an abbreviation; the nearby legend
  defines `R=OUT_RED`, `I=OUT_IR`, `V=3V3`, `N=NC`, and `GR/GI=channel GND`.
  D1/D2 also show `K` and `A`. Pin numbers are deliberately omitted from the
  rear labels. Read the mirrored rear silkscreen while
  looking directly at the rear.
- Fit the 22 pF parts as C0G/NP0, not X7R.
- Trim through-hole leads on the rear to at most 2 mm for the slide-in frame.
- If the output sits near 3.3 V under normal illumination, replace R1/R2 with 330 kohm. Do not parallel the RED and IR outputs.

## Generated evidence

- `reports/erc.rpt`: schematic electrical-rule check.
- `reports/drc.rpt`: PCB DRC, unconnected-item and schematic-parity check.
- `reports/pin_contract.json`: exact net/pin and mechanical contract audit.
- `reports/schematic.pdf` and `reports/schematic.png`: readable schematic.
- `reports/pcb_top.png`, `reports/pcb_bottom.png`: PCB renders.
- `reports/wiring_guide.png`: routing and pad-number guide.
- `fabrication/`: Gerbers and plated/non-plated drill files.
- `mechanical/`: adapter STLs, collision report and nominal optical report.

The CAD checks do not prove analog gain, noise, optical leakage, print shrinkage or physical fit. Measure the real LED current/output and perform a dark-box leakage test before ordering a large batch.

## Compact mechanical revision v1.4

Use `mechanical/frame_70x20_bpw34_print.stl`; see mechanical/README.md.

## Bố trí bản thu gọn hiện tại

PCB 70 × 20 mm, không có lỗ bắt vít. Tâm BPW34 tại (15,75;11,7)/(54,25;11,7) mm; hàng header Y=16,667 mm. Tất cả R/C ở mặt sau. Đường đồng ngang/dọc, vòng SUM và hồi tiếp giữ ngắn. Dùng riêng gá BPW34 có bậc Y thế giới=23,7 mm để giữ trục quang Y=32 mm; không dùng gá OPT101. Các bảng vị trí cũ được thay bởi tọa độ PCB và fit_report.json hiện tại.

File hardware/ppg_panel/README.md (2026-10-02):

# Panel V-cut PPG — 70 × 80 mm

Mở `ppg_panel.kicad_pro` / `ppg_panel.kicad_pcb` bằng KiCad 10.
Đây là **panel gia công gồm ba thiết kế khác nhau**, mỗi thiết kế một bản:

| Vị trí từ cạnh trên | Board sau tách | Kích thước |
|---|---|---|
| Y = 0–20 mm | OPT101 receiver v1.5 | 70 × 20 mm |
| Y = 20–40 mm | BPW34 receiver v1.4 | 70 × 20 mm |
| Y = 40–80 mm | LED/IR driver v1.9 | 70 × 40 mm |

Hai đường V-cut ở **Y = 20 và 40 mm**, chạy thẳng hết chiều ngang 70 mm.
Tọa độ trong file KiCad: góc trên trái (50,50); các đường cắt Y=70 và 90.
Không có khe phay giữa board: V-cut dùng chung đường biên, khoảng hở cơ khí
trước khi bẻ bằng 0. Sau khi tách là ba PCB độc lập. Toàn bộ đồng, pad, via
và vùng đồng cách tâm đường cắt ít nhất **1,5 mm mỗi phía**; không có đường
điện xuyên qua đường cắt. Các net và reference trong panel được đặt tiền tố
OPT/BPW/TX để không nối nhầm GND hoặc nguồn giữa các board.

**Chỉ dẫn nhà in:** FR-4 dày 1,6 mm, 2 lớp đồng 1 oz, soldermask hai mặt,
silkscreen trắng hai mặt. `Edge_Cuts` là duy nhất đường bao phay ngoài.
File `ppg_panel-User_Comments.gbr` chỉ chứa hai **tâm đường V-score hai mặt**;
không coi là lớp đồng, không phay thành hai khe xuyên. Bản vẽ
`reports/vcut_drawing.pdf` giải thích vị trí và kích thước. Nhà in chọn độ
sâu V-score theo quy trình FR-4 1,6 mm và xác nhận dung sai/khoảng hở của họ.
Tách panel trước khi hàn/cắm IC, module và photodiode; làm sạch phần ba via
ở mép bẻ nếu cần. Không cấp điện cho cả panel như một board hệ thống.

Diện tích PCB giảm **75,6 → 56 cm² (25,93%)**. Đây là giảm diện tích thực,
không phải bảo đảm giảm giá tương ứng: cần báo đúng **3 designs / panel**,
vì nhà in có thể tính phí ghép thiết kế hoặc V-cut. Không cần thanh biên cho
bộ PCB trần này; nếu nhà in yêu cầu thanh biên thì diện tích báo giá tăng.

## Kiểm tra

- Cả ba source: ERC/DRC và đối chiếu schematic–PCB.
- Panel: DRC, 0 kết nối thiếu; kiểm tra độc lập net, pad, drill, vị trí và
  từng đoạn đồng so với source, khoảng hở lỗ khoan và V-cut.
- `reports/panel_audit.json` chứa bề rộng đường theo từng net và khoảng cách
  tới từng lỗ; `reports/manifest.json` lưu SHA-256 của ba PCB nguồn.
- `ELECTRICAL_REVIEW.md` giải thích đường nguồn, RC và những giới hạn điện
  chưa thể chứng minh bằng CAD. DRC sạch không chứng minh mạch đã chạy thật.

Schematic vẫn ở ba project riêng. Không cập nhật panel từ một schematic
trống và không sửa điện trực tiếp trong panel. Sau khi sửa source, chạy
`build_panel.py`, DRC refill, `verify_panel.py`, rồi xuất lại Gerber/drill.
Scripts dùng Python có `pcbnew` của KiCad 10.

## Gá in 3D mới

Hai receiver dùng hai biến thể thanh U trong `docs/system_3d/out/print_bambu_180/`:
`14_ga_chu_U_OPT101_70x20.stl`, `15_ga_chu_U_BPW34_70x20.stl`.
Driver dùng `16_ga_driver_70x40.stl`. Xem mechanical/README.md của từng project.
Trục quang danh nghĩa và khoảng cách hai kênh 38,5 mm được giữ nguyên.

## Khoảng hở khi tách panel

Đồng cách tâm V-cut ≥1,5 mm mỗi phía. Bao footprint các R/C cách V-cut ≥2 mm (bản hiện tại ≥2,095 mm), có kiểm tra tự động trong verify_panel.py. Không thay điều này cho giới hạn cơ khí của nhà in. Tách panel trần trước khi hàn, dùng dụng cụ tách V-score để hạn chế uốn PCB gần tụ gốm; không bẻ mạnh panel đã lắp linh kiện.

## Layout 45°

Ba board và panel đã vát góc rẽ dây 45°. Xem [đánh giá bố trí hai mặt và V-score](LAYOUT_REVIEW.md).

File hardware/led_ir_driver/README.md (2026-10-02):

# DATN: PPG-Simulator — LED / IR driver v1.9

Mở `led_ir_driver.kicad_pro` bằng KiCad 10. Board hai lớp, **70 × 40 mm**,
FR4 1,6 mm; socket module, socket IC và header xuyên lỗ; toàn bộ điện trở và tụ điện là linh kiện dán.
Thư viện symbol, footprint, mô hình 3D đi kèm trong thư mục dự án.
Schematic v1.9 dùng dây nối trực tiếp cho từng kênh và nhãn net cho bus chung,
không kéo dây xuyên qua thân header. Đọc `ELECTRICAL_AUDIT.md` để xem kết quả
rà soát điện, cấu hình ADDR và các điều kiện trước khi cấp nguồn. Đọc
`COMPONENT_RATIONALE.md` để hiểu lựa chọn linh kiện và `PIN_MAP.md` để tra
chân nối; `reports/wiring_guide.png` thể hiện đường đồng hai lớp có màu.

Mặt sau PCB ghi tên tín hiệu cạnh từng pad của J1/J2/J3/J4, J5/J6/J7, socket
LM358 và hai transistor. Nhãn chân không có tiền tố số; tên connector và
reference linh kiện vẫn được giữ để đối chiếu schematic.

Xem `CONNECTIVITY_REVIEW.md` để xem đường GND, bus chung và thay đổi một đầu cáp ở v1.3.

## Cắm module và dây

Thứ tự dưới đây đúng theo ảnh module người dùng xác nhận; đọc từ đầu OUT
ở trên xuống GND ở dưới khi nhìn mặt linh kiện. **Pad 1 PCB là OUT**;
pad vuông SCL trên chính module không phải dấu pin 1 của socket PCB.
Module nằm ngang, mặt linh kiện hướng lên; thân module mở rộng sang phải
của hàng socket như ảnh. Hàn hàng chân đực xuống mặt dưới module để cắm.

| Pad | J1 socket IR / J2 đầu cáp Pi | J3 socket Red |
|---|---|---|
| 1 | OUT IR | OUT Red |
| 2 | GND | GND |
| 3 | SCL | SCL |
| 4 | SDA | SDA |
| 5 | 3,3 V | 3,3 V |
| 6 | GND | GND |

J1–J2 nối **1:1 đủ sáu chân**. J3 dùng chung GND, 3,3 V, SCL và SDA
với J1/J2; OUT Red chỉ đi từ J3 vào mạch Red, không nối OUT IR.
J2 là header đực duy nhất để đưa I²C/3,3 V từ Pi vào board.
**Bẹ I²C bốn lõi vào chân 3–6: SCL, SDA, 3V3, GND; không vào 1–4.**
J4 là header đực 1×2 bước 2,54 mm: chân 1 = OUT_RED, chân 2 = GND. J2.1/J2.2 là OUT_IR/GND. Nhóm I²C 2,00 mm của J2 vẫn là đầu cáp Pi dùng chung.
Pin OUT là ngõ ra DAC để đo/lấy tín hiệu, không nối vào ngõ ra khác.

Hai chân GND của mỗi module (pin 2 và pin 6) nối vào vùng đồng GND mặt dưới.
Vùng này cũng nối J2.2/J2.6, LM358 pin 4, đầu dưới các điện trở sense,
cực âm C5/C7 và J7.2. Vì vậy nguồn 5 V tại J7 phải chung GND với Pi.

Đặt jumper địa chỉ trên module: **IR = 0x60, Red = 0x61** theo cấu hình source.
Với module MCP4725A0: IR đặt ADDR về GND, RED đặt ADDR về VCC (3,3 V).
Gỡ cầu hàn ADDR–GND nếu có trước khi nối ADDR–VCC; không nối tắt cả ba pad.
Hai chân GND của module vẫn giữ chung GND ở cả hai cấu hình địa chỉ.
Header sáu chân không đưa chân ADDR ra ngoài. Kiểm tra jumper và quét I²C
trước khi chạy; không để hai module cùng địa chỉ. Module đã có pull-up I²C,
board không thêm pull-up; cần kiểm tra tải pull-up khi dùng chung Grove HAT.

| Đầu nối | Pin 1 | Pin 2 |
|---|---|---|
| J5 LED IR | Anode LED, +5 V | Cathode LED, collector Q1 |
| J6 LED Red | Anode LED, +5 V | Cathode LED, collector Q2 |
| J7 nguồn | +5 V | GND |

J5/J6/J7 dùng header đực 1×2 bước 2,54 mm. LED nằm trên carrier trong hộp
quang, nối bằng dây. Cathode LED không nối trực tiếp xuống GND.
Nguồn 5 V chỉ cấp LM358 và LED; **không có 5 V ở header MCP4725**.
Driver và RX dùng dây nguồn/GND riêng về Pi/HAT; không nối tiếp đường hồi
dòng LED qua board OPT101/Grove ADC. Trước khi cấp nguồn, xác nhận cực LED
và chiều cắm IC/socket theo rãnh pin 1 ở phía trên board.

## Mạch điều khiển dòng

U1 là **LM358P PDIP-8** với socket rộng 7,62 mm. Q1/Q2 chọn **2N4401 TO-92**
theo datasheet onsemi: pad 1 emitter, pad 2 base, pad 3 collector.
Footprint rộng 2,54 mm mỗi chân, cần uốn chân theo lỗ; đối chiếu mặt phẳng
vỏ và datasheet linh kiện mua thực. **C1815 không thay trực tiếp** vì E–C–B.

Hai điện trở 10 kΩ 1% chia đôi điện áp DAC. LM358 điều khiển base qua 1 kΩ
để giữ điện áp emitter bằng điện áp command. R4 = 100 Ω cho IR, R9 = 100 Ω
cho Red, điện trở dán **1206, 1%, công suất danh định tối thiểu 0,25 W**.

`I_emitter ≈ V_DAC / (2 × R_sense)`.
Tại nguồn DAC 3,28 V và gần full-scale: khoảng 16,40 mA IR / 16,40 mA Red.
Nguồn 3,30 V cho khoảng 16,50 mA / 16,50 mA. Dòng LED collector nhỏ hơn bởi
dòng base; đây là tính toán danh nghĩa, chưa gồm sai số và chưa đo thực.

C5 là tụ gốm dán **0805, 100 nF X7R 50 V**, không phân cực.
C7 là tụ hóa dán **SMD 5×5,4 mm, 10 µF ≥16 V**; kiểm tra đúng kích thước
thân/chân của linh kiện mua, cực + nối 5 V và cực − nối GND. C5 đặt sát nguồn U1; C7 gần đầu nguồn. Tụ hóa C7 là
tụ phân cực; không phải hai loại linh kiện riêng cần lắp thêm.

Các vị trí **DNP — chưa lắp**:

- C2/C4: bù vòng từ OUT op-amp về ngõ đảo, chỉ chọn sau kiểm tra oscilloscope.

Đã bỏ C1/C3, R5/R10 (trước đây đều DNP) và tụ bypass đầu nguồn C6 khỏi
v1.3. Lắp mặc định **8 điện trở, C5 và C7**, không lắp C2/C4. Giữ tên
reference cũ để dễ đối chiếu, nên có số thứ tự khuyết trong BOM.

Không khẳng định vòng ổn định chỉ từ ERC/DRC. Kiểm tra dòng, dao động,
overshoot và sai lệch ở DAC thấp/cao trước khi dùng. MCP4725 nạp giá trị
EEPROM khi khởi động nên LED có thể sáng trước khi phần mềm đặt DAC về 0;
board này không có khóa tắt LED độc lập. Không ghi EEPROM trong luồng phát.

## Cơ khí và hình xem trước

Board mới 70 × 40 mm, lỗ tại (4,24), (66,24), (4,36), (66,36) mm, Ø3,2 mm. Dùng gá chuyển `mechanical/driver_70x40_adapter_print.stl` để lắp lên đế 70 × 55 mm cũ; xem `mechanical/README.md` về chiều lắp và vít.
Các đầu ra LED nằm sát cạnh hướng về hộp quang theo mô hình driver cũ.

Ảnh module xác nhận pinout nhưng không cho kích thước cơ khí chính xác.
Đường bao module trên Dwgs.User chỉ là vùng dự kiến; cần đo chiều rộng,
vị trí hàng chân và thử trên bản in 1:1 trước khi gia công. Chưa xác nhận
va chạm với linh kiện/đầu cáp thực hoặc độ co của đế in.

Ảnh 3D `reports/pcb_top.png` hiển thị socket rỗng, chưa gắn hai module và
LM358. Mặt sau có đúng tên đồ án và tác giả trong `reports/pcb_bottom.png`.
Schematic có bản SVG, PNG và PDF trong `reports/`. U1A/U1B/U1C trên schematic
lần lượt là hai kênh khuếch đại và chân nguồn của **cùng một IC U1**.

## Kiểm tra và file gia công

KiCad 10.0.6: **ERC 0 lỗi/0 cảnh báo; DRC 0 vi phạm; 0 kết nối còn thiếu;
0 sai khác schematic/PCB; 244 kiểm tra hợp đồng chân, giá trị, hình học và đi dây đạt**.
Số lượng/cỡ lỗ theo `reports/drill.rpt`; bốn lỗ bắt vít Ø3,2 mm.

- `reports/erc.rpt`: kiểm tra schematic.
- `reports/drc.rpt`: DRC và parity schematic/PCB.
- `reports/pin_contract.json`: kiểm tra độc lập pinout, nguồn, hồi tiếp,
  header 1:1, footprint, DNP và kích thước.
- `fabrication/`: Gerber và drill. `../PPG_LED_IR_driver.zip`: gói board lẻ. Panel ghép mới nằm trong `../PPG_3boards_VCUT_panel.zip`.
- `BOM.csv`: danh sách footprint trên board; mua thêm hai module MCP4725,
  một LM358P và hai socket cái 1×6, một socket DIP-8 theo BOM.

File đã xuất để kiểm tra; chưa gửi đặt sản xuất. Phần cứng và đặc tính
quang/điện chưa được đo. Không coi DRC sạch là chứng minh mạch hoạt động.

## Tái sinh

`generate_design.py` ghi đè schematic và PCB, **xóa chỉnh sửa thủ công**.
Không cần chạy script để mở/chỉnh dự án bằng KiCad. `schematic_connected.py`
vẽ schematic bằng dây nối; `route_board.py` đặt từng đoạn đồng đã chọn theo
chức năng, không sử dụng autorouter. Sau khi sinh cần refill zone và chạy
ERC/DRC/parity; `verify_design.py` kiểm tra độc lập các kết nối dự định.
`render_wiring.py --export` chạy bằng Python có pcbnew; sau đó chạy cùng
script không tham số bằng Python có matplotlib để xuất bản đồ đường dây.

Nguồn: sơ đồ `docs/hardware/PPG_PROTOTYPE_SCHEMATIC.md`,
[2N4401 onsemi](https://www.onsemi.com/pdf/datasheet/2n4401-d.pdf),
datasheet MCP4725 và LM358 trong `docs/ds_linhkien/`.
Footprint/model từ KiCad 10: CC-BY-SA 4.0 với ngoại lệ sử dụng trong thiết kế
điện tử, [KiCad Library License](https://www.kicad.org/libraries/license/).

## J2 revision v1.4

J2 gồm hai đoạn header đực rời: OUT/GND (pad 1–2) bước 2,54 mm; SCL/SDA/3V3/GND (pad 3–6) bước 2,00 mm. Khoảng cách tâm pad 2 đến pad 3 là 3,96 mm để tách hai thân nhựa. Mua một header 1×2 2,54 mm và một header 1×4 2,00 mm, không dùng một thanh 1×6. Socket cái J1/J3 vẫn bước 2,54 mm.

## Bố trí bản thu gọn hiện tại

PCB 70 × 40 mm. Lỗ PCB tại (4;24), (66;24), (4;36), (66;36) mm. C7 đặt mặt sau giữa các header, các tụ/trở còn lại dùng footprint SMD. Đường đồng ngang/dọc; nguồn 5 V rộng 0,60–0,80 mm. Tọa độ hiện tại trong PCB/fit_report.json thay cho bảng vị trí cũ.

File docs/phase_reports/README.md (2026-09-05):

# Validation reports

Only reports that describe the current implementation belong here.

- [V5 continuation and validation](V5_CONTINUATION_REPORT.md)

Historical phase prompts and intermediate completion notes are available in Git
history. They were removed from the source tree because their ranges, UI paths,
test counts and implementation status no longer match version 5.

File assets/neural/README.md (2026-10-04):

# Neural PPG assets

The current page 04 keeps the three-Gaussian option and provides the LSM-GAN
v2 generator for experimental 30-second sequence generation. LSM inference
uses `lsm_generator.ts`; its 1,200-sample output is native 40 Hz. The app maps
that normalized shape onto nominal IR/RED levels. It does not learn separate
optical channels or calibrated SpO₂.

The cWGAN-GP and TCN-FiLM artifacts are retained for offline research and
historical comparisons; they are not selectable on the current page. cWGAN
generates one condition-controlled, 256-point phase pulse. Its pilot export
does not contain the trained critic. The original Gaussian engine remains
available without PyTorch.

Install `requirements/neural.txt` only when running neural inference. Do not
copy an x86 virtual environment onto a Raspberry Pi; recreate it for the Pi's
Python and ARM64 platform. `manifest.json` records model hashes and preprocessing
metadata for the packaged LSM asset. Other model files may be ignored by Git;
check the manifest, `.gitignore` and [round 2 report](../../docs/ppg_round2_report_2026-09-28.md)
before expecting research artifacts to be present in a checkout.

Training data is BIDMC 1.0.0, not paired raw IR/RED or a broad healthy cohort.
Validation is exploratory because the test set was previously viewed; cWGAN
single pulses and LSM long sequences are not directly equivalent. The current
page's DAC playback is an explicit user action; opening the page or generating
a preview alone does not emit output. See the [LSM report](../../docs/ppg_lsm_gan_report_2026-09-26.md)
and [sequence and hardware validation](../../docs/ppg_touch_sequence_output_2026-09-30.md).

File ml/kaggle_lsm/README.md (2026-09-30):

# LSM-GAN comparison: implementation contract

Independent research reimplementation informed by [Ding et al., arXiv v2](https://arxiv.org/abs/2108.05272v2)
and [author code](https://github.com/chengding0713/Log-Spectral-matching-GAN/tree/d2d01feab0cec7c129bae0b63c56277adc4f48cc).
This is not a reproduction of the paper's AF classifier results. Source code
from the author repository is not vendored; implementation differences are
explicit below. Existing cWGAN code and v1 results remain unchanged.

Kaggle version 2 completed all three 1,500-step arms on T4. Artifacts are in
`ml/runs/lsm-kaggle-v2/lsm_comparison/`; see the [Vietnamese results report](../../docs/ppg_lsm_gan_report_2026-09-26.md).
The matched BCE spectral-loss arm reduced mean log-PSD RMSE from 2.03235 to
1.73491, but ACF MMD² did not improve and real/generated spectra still differ.
All exports passed local G/D parity checks; no model is approved for DAC use.

## Why a separate experiment

The current product learns a **conditioned single pulse** at 256 phase points.
LSM uses **30-second segments at 40 Hz**, with noise and output length 1200.
Spectral block self-consistency concerns multiple beats. Applying it blindly
to systolic and diastolic parts of one pulse would impose the wrong target.

LSM here has no condition inputs. In particular, it does not yet offer HR,
SP/DN/DP, SpO2 or disease controls. Its output length has a physical time scale
because its training windows retain Fs=40 Hz, unlike the phase-only cWGAN.
Resampling output does not make arbitrary clock rates learned capabilities.

## Discriminator/critic architecture

| Model | Network | Parameters | Output |
|---|---|---:|---|
| Existing cWGAN v1 critic | Conv1D 8→16→32→32, kernel 7/stride 2, LeakyReLU; Flatten→Linear 1024→1 | 12,753 | Unbounded score; no sigmoid/BatchNorm |
| LSM discriminator | Conv1D 1→64→128→256→512, kernel 4/stride 2; BN after stages 2–4, LeakyReLU; Conv 512→1; Linear 72→2 | 692,370 | Two sigmoid real/fake scores |

The critic's 8 input channels are one waveform plus seven broadcast condition
values. LSM's two outputs BOTH use real=1/fake=0 targets; they are **not AF
and non-AF classes**, and do not sum to one. This unusual head is retained
from the reference topology. Discriminator size alone does not establish
that it is superior. The larger D is used only for training/evaluation, not
needed in the Pi generation loop.

LSM generator: parallel same-length convolution branches (kernel/channels
5/80, 21/40, 61/20), concatenation, 15/50 merge, 4/50 then 2/1 output
convolutions with tanh and per-window minmax. No upsampling. Parameter count
117,940. Denominator guards are added for numerical stability.

## Paper and code are not identical

| Arm | Adversarial objective | Spectral matching | Weights match/self |
|---|---|---|---|
| `lsm_paper` | Least squares, following paper equation 3 | Same-position blocks | 1 / 1 |
| `lsm_repo_corrected` | BCE, as in released training script | All real/fake block pairs | 1 / 1 |
| `dcgan1200_no_spectral` | BCE | Disabled | 0 / 0 |

The paper supplies the objective and multi-block matching concept; the
released `models_1200.py` supplies the detailed layer dimensions. All three
arms use the same G and D topology, initialization, batches, seeds, validation
noise, training budget and selection metric. The code-matched arm and
no-spectral control isolate adding spectral loss; comparing paper vs code
arms changes both adversarial loss and pairing, so cannot isolate either one.
Equation 3 explicitly specifies the generator objective. For `lsm_paper`,
the matching least-squares D objective is a declared implementation choice;
the released training script instead supplies BCE for both networks.

Spectral implementation follows the released loss's log-power interpretation:
400-sample periodic Hann windows multiplied by 2, hop 200, five blocks per
segment; `torch.fft.rfft`, squared magnitude, clamped log, per-sample/block
frequency minmax. Mean squared distances are averaged across batch and
frequency; block aggregation is mean. Self-consistency compares distinct
generated blocks (i<j). It is NOT the logarithm of an MSE waveform loss.

Corrections/adaptations rather than literal source replication:

- Reference `torch.rfft` is obsolete; replaced by `torch.fft.rfft`.
- Reference frequency normalization reshapes memory using `view(-1,batch)`,
  mixing observations; normalization here preserves batch independence.
- Clamp power before log and guard ranges instead of permitting log(0)/NaN.
- Revision 2 keeps D in train mode during the G-only update while freezing
  parameter gradients, consistent with the reference. Revision 1 instead
  used eval-mode D for this step, creating a train/eval objective mismatch;
  that run is retained as a diagnostic, not the primary comparison.
- Adam 5e-4, betas (.5,.999) from released script; batch 64, 1,500 G/D update
  pairs and fixed weights 1/1 for this bounded pilot. No original large grid
  search, AF-specific weights, learning-rate schedule or AF classifier.
- Checkpoint selection uses validation ACF-MMD² + log-PSD-MMD², not the exact
  original hyperparameter search. No test-based checkpoint selection.

Thus `lsm_paper` means a **paper-objective variant on the reference topology**,
not exact paper replication. The original clinical dataset and private AF
annotations are not available here. No AF efficacy claim is made.

## Data and comparison limits

[BIDMC 1.0.0](https://physionet.org/content/bidmc/1.0.0/), Pimentel et al.,
DOI:10.1109/TBME.2016.2613126, ODC Attribution 1.0. Reuse frozen v1 patient
groups: 32/7/7 train/validation/test, including repeated recordings grouped
under the same person. 125 Hz source → `resample_poly(8,25)` → 161-tap
zero-phase FIR 0.9–5 Hz → non-overlapping 30 s → minmax per segment.
The FIR tap count/phase choice is an explicit project choice, not an exact
filter specification given by the paper. 624/112/112 windows result. No
filtering of AF/NSR or manual artifact labels is claimed.

Metrics: biased RBF MMD² of normalized ACF (lags 1..200 at 40 Hz), MMD² of
normalized log-Welch power, mean log-spectrum RMSE, dominant frequency in
0.5–3 Hz expressed as BPM, power >5 Hz, roughness and pointwise diversity.
Kernel bandwidths are median squared distances on **training** features only.
Dominant frequency can be a harmonic and is not an ECG-validated heart rate.
Discriminator real/fake scores are diagnostics, not clinical quality labels.

The same test patients were inspected in the earlier pilot. This is an
exploratory engineering comparison, not a new independent confirmation.
Single seed, limited data, no confidence intervals, and unequal contributions
per patient limit conclusions. No-spectral ablation is the strongest matched
comparison; all checkpoints are selected without reading test metrics.

Existing cWGAN is additionally evaluated by drawing conditions from TRAIN,
rendering repeated pulses at constant HR for 30 s, applying the FIR view and
normalizing. Real train pulses use the same adapter. Real train 30 s windows
are a separate replay baseline. These adapters impose periodicity and a
band limit, unlike raw LSM outputs; they cannot establish which GAN is better
at generating full rhythm variability or notch control. Their previous
training budget and checkpoint criterion also differ. Filtered 40 Hz strips
must not inherit the prior 256-point notch scores without fresh validation.

## Run

```bash
# CPU smoke test; choose a new directory each time
.venv-ml/bin/python -m pytest tests/test_ml_ppg.py tests/test_lsm_gan.py -q
.venv-ml/bin/python ml/kaggle_lsm/train_lsm.py --steps 2 --batch 4 --output ml/runs/lsm-smoke-new

# Private Kaggle run; consumes GPU quota, bounded to 30 minutes
uv tool run --from kaggle kaggle kernels push -p ml/kaggle_lsm --timeout 1800 --accelerator NvidiaTeslaT4
uv tool run --from kaggle kaggle kernels status charlesday2612/ppg-lsm-gan-bidmc-comparison
uv tool run --from kaggle kaggle kernels logs charlesday2612/ppg-lsm-gan-bidmc-comparison
uv tool run --from kaggle kaggle kernels output charlesday2612/ppg-lsm-gan-bidmc-comparison -p ml/runs/lsm-kaggle-v2
.venv-ml/bin/python -m ml.audit_lsm_run ml/runs/lsm-kaggle-v2/lsm_comparison
```

Only the standalone new script is uploaded. Prior pilot artifacts are mounted
through `kernel_sources`. The mounted prior training-code hash is checked;
its generator hash is recorded. The MAT source checksum is verified again.
Private user config/hardware/credentials are not uploaded.

Each arm saves `best.pt` (G **and D**), `last_training_state.pt` (G/D,
optimizers and RNG states), `generator_cpu.ts`, `discriminator_cpu.ts`, logs,
metrics and samples. RNG states are saved for future resume support; the CLI
does not implement `--resume` yet. Comparison outputs include `configuration.json`,
`manifest.json`, `windows.npz`, `comparison.json` and `comparison.png`.
The local audit also creates a 30 s `example_ir_red_40hz.csv` per arm, using
one shared learned shape, 1.5 V pedestals, AC_IR=45 mV and AC_RED=21.6 mV.
These are offline examples under nominal calibration, not learned paired
optical channels, commanded HR traces, or signals sent to the DAC.
No automatic update of the production engine or DAC output occurs.

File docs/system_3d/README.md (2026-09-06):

# PPG Simulator — mô hình cơ khí v4

Nguồn tham số: [build_system.py](build_system.py). Bản v4 sửa khẩu độ, nắp,
bổ sung trục đẩy tròn vào STL và kiểm tra lại đường lắp ráp hai làn quang.
Báo cáo: [MECHANICAL_V4_REVIEW.md](MECHANICAL_V4_REVIEW.md).

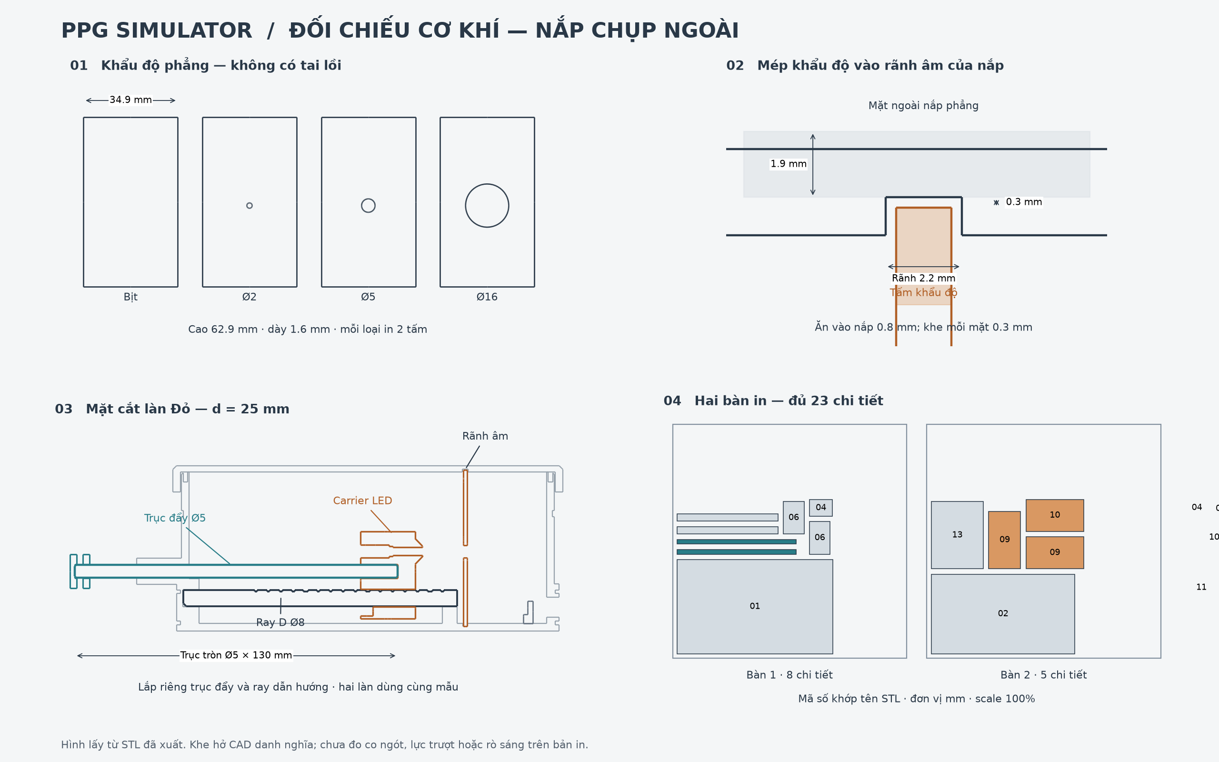
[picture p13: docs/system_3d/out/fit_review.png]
Các chi tiết và mặt cắt lắp ráp v4


## File dùng để in

**Dùng bộ v4 trong [out/print_bambu/](out/print_bambu/), đơn vị mm, tỷ lệ 100%.**
Tải trọn bộ: [print_bambu_v4.zip](out/print_bambu_v4.zip).
In mỗi bàn dưới đây **một lần**; số lượng hai làn đã được xếp đủ:

| Bàn | Nội dung | Kích thước bao STL, X × Y × Z (mm) |
|---|---|---|
| [00_ban_1_co_khi.stl](out/print_bambu/00_ban_1_co_khi.stl) | 14 chi tiết cơ khí: thân, nắp, 2 ray D, 2 carrier, 2 núm, 2 trục tròn, 4 chụp | 213.5 × 239 × 64 |
| [00_ban_2_khau_do_khung.stl](out/print_bambu/00_ban_2_khau_do_khung.stl) | 8 khẩu độ + 1 khung board | 235.5 × 211.2 × 4 |

Tổng **23 chi tiết**. Khi lắp chỉ dùng **một khẩu độ mỗi làn**, sáu tấm còn lại
là phương án thay thế. Bản cũ `00_ppg_hop_toi_A1_all_in_one.stl` chỉ có một bản
của mỗi chi tiết, thiếu trục đẩy và khung board; đã được thay bằng hai bàn trên.
File ZIP cũ đã tải trước v4 cần được thay bằng bộ mới.

Nếu in từng STL riêng, dùng số lượng sau (không in thêm hai bàn gộp):

| File trong `out/print_bambu/` | Số lượng | Kích thước in X × Y × Z (mm) |
|---|---:|---|
| `01_than_hop_toi.stl` | 1 | 170 × 103 × 64 |
| `02_nap_labyrinth.stl` | 1 | 150 × 80 × 6.8 |
| `03_truc_truot_D.stl` | 2 | 110 × 8 × 6.5 |
| `04_carrier_led.stl` | 2 | 25 × 18 × 35 |
| `05_num_thanh_truot.stl` | 2 | 16 × 15.52 × 8 |
| `06_chup_luon_day_trai.stl` | 2 | 22.5 × 35.5 × 16.5 |
| `07_chup_luon_day_phai.stl` | 2 | 22.5 × 35.5 × 16.5 |
| `08_khau_do_biet.stl` | 2 | 62.9 × 34.9 × 1.6 |
| `09_khau_do_lo2mm.stl` | 2 | 62.9 × 34.9 × 1.6 |
| `10_khau_do_lo5mm.stl` | 2 | 62.9 × 34.9 × 1.6 |
| `11_khau_do_lo16mm.stl` | 2 | 62.9 × 34.9 × 1.6 |
| [12_truc_day_tron_D5x130.stl](out/print_bambu/12_truc_day_tron_D5x130.stl) | 2 | 130 × 5 × 5 |
| `13_khung_board_5x7.stl` | 1 | 56.8 × 73.4 × 4 |

[manifest.json](out/print_bambu/manifest.json) ghi kích thước, số lượng,
vị trí trên bàn và SHA-256 của từng STL. Hai bàn chừa tối thiểu 8 mm mép bàn,
khe giữa các footprint tối thiểu 6 mm; chưa bao gồm brim/support do slicer sinh.

`out/stl/` chứa **16 mẫu STL theo hệ lắp ráp Y hướng lên**. Chúng dùng cho
kiểm tra hình học, cần chọn lại tư thế nếu mở trực tiếp trong slicer. Các mẫu
`*_red` dùng chung cho Đỏ và IR, in hai bản. Ngoài bộ hộp tối, thư mục này có
`base_neg.stl` ×1, `base_pos.stl` ×1, `screen_foot_1.stl` ×2 để in đế hệ thống.
Hai bàn Bambu ở trên không chứa đế và chân màn hình.

## Các khớp lắp đã sửa

- **Khẩu độ:** tấm chữ nhật phẳng dày 1.6 mm, không còn tai cầm hoặc phần lồi
  trên hai mặt. Mép trên ở Y=64.8 mm; mở nắp rồi cầm mép tấm bằng nhíp để đổi.
- **Nắp:** mặt ngoài phẳng, bỏ hai vấu giữ khung board. Giữ mộng labyrinth quanh
  chu vi và vách giữa. Hai rãnh âm 2.2 mm rộng, sâu 1.1 mm nhận mép khẩu độ;
  phần ăn vào rãnh 0.8 mm, khe đỉnh 0.3 mm. Mái rãnh còn 1.9 mm nhựa đặc.
- **Khung board:** trượt giữa vai trước/sau nằm trên thân. Vai trước cách khung
  0.3 mm; nắp không cần vấu nhô xuống để giữ khung.
- **Trục tròn:** Ø5 × 130 mm, vát hai đầu 0.4 mm; đã có STL. Một trục cho mỗi
  carrier, độc lập với ray D Ø8 bên dưới. Có thể thay bằng thanh thép cùng
  kích thước; bản in cần kiểm tra độ thẳng, độ cứng và ba-via sau in.
- **Lỗ giữ trục ở carrier/núm:** Ø5.4 mm, khe danh nghĩa 0.2 mm mỗi phía;
  giữ bằng vít chặn, không trông chờ vào ép chặt nhựa. Carrier dùng M3×8,
  núm dùng M3×6, mỗi làn một vít ở mỗi vị trí.
- **Gối ray D:** mở phía trên ở đầu +X, để hạ ray từ nóc rồi trượt sang trái
  3 mm vào lỗ mù. Mặt phẳng ray D đã được xoay xuống đúng bàn in.
- **Lỗ luồn dây:** dao cắt đã đi xuyên cả mặt ngoài và mặt trong của bốn cửa
  cáp. Lớp nhựa bịt ở mặt vách của bản cũ đã được bỏ. Chụp vẫn có mộng kín.

## Kích thước hệ lắp ráp

Hệ trục: +X dọc LED → OPT101; +Y lên trên; +Z ngang. Tâm làn Đỏ ở Z=−19.25,
IR ở Z=+19.25; trục quang Y=32. Mặt trước phía người ngồi là −Z.

| Thành phần | Kích thước/vị trí danh nghĩa (mm) |
|---|---|
| Thân + nắp, không tính tai và bệ | 150 × 67 × 80 (X × Y × Z) |
| Thân kể cả tai và bệ dẫn trục | X=−18..152, Y=0..64, Z=−51.5..51.5 |
| Ray D | X=1..111, tâm Y=14, Ø8, mặt phẳng Y=16.5 |
| Trục đẩy | tâm Y=24, Ø5, dài 130 |
| Khẩu độ | X=113.4..115.0, Y=1.9..64.8, rộng Z=34.9 |
| Rãnh khẩu độ thân | X=113.2..115.2; khe 0.2 mỗi mặt |
| Khung board | X=137.5..141.5, Y=3..59.8, Z=−36.7..36.7 |
| Cửa sổ OPT101 | X=120, Y=32, Z=±19.25 |
| Hành trình khoảng cách chóp LED → OPT101 | d=15..90; mặc định Đỏ 25, IR 85 |
| Đế chung | 198 × 288, chia hai nửa ở Z=0 |
| Hai chân màn hình | tâm X=20/130, Z=−190..−136; máng rộng 21, nghiêng 15° |

**Đọc khoảng cách:** đầu đuôi trục ở X=−18−d. Núm ôm 6 mm cuối trục nên
khoảng thanh trần giữa mặt bệ và mặt trong núm là **d−6 mm**; đo khoảng này
rồi cộng 6 mm để ra d. Ví dụ d=25 → khe 19 mm. Công thức chỉ đúng khi trục
cắm hết 15 mm vào carrier và 6 mm vào núm. Ở d=90, núm tới X=−110: chừa
không gian thao tác bên trái đế.

## Trình tự lắp

1. Để mở nắp, chưa lắp khẩu độ/khung board. Luồn carrier lên mỗi ray D. Đặt
   ray lệch +X 3 mm, hạ xuống gối mở phía trên, rồi đẩy −X 3 mm cho đầu ray
   vào lỗ mù. Xoay mặt phẳng D lên trên trong hệ lắp ráp.
2. Lắp LED, bố trí chân và dây qua khe hông carrier. Luồn trục Ø5 từ bên ngoài
   qua bệ, cắm hết 15 mm vào carrier; siết vít chặn M3×8 trước khi đóng hộp.
3. Lắp núm vào 6 mm cuối trục, siết M3×6. Đẩy/kéo kiểm tra cả hai đầu hành trình.
   Lỗ vít là lỗ mồi Ø2.6 để tạo ren M3 trong nhựa; không siết quá mức làm nứt.
4. Đưa khung board và board cảm biến vào giữa hai vai trên thân. Các kích thước
   PCB/module/đầu cắm còn gắn `[ASSUME]` trong mã cần đối chiếu linh kiện thật.
5. Đặt một khẩu độ mỗi làn xuống đáy rãnh. Hạ nắp thẳng đứng: mép tấm vào rãnh
   âm, mộng nắp vào rãnh thân. Nếu chưa xuống hết, nhấc lên kiểm tra thay vì ép.
6. Luồn dây đúng cửa rồi lắp bốn chụp. Chụp có bốn trụ Ø4 nhận vào lỗ Ø4.3 và
   mộng vòng; đây là khớp có khe hở, độ giữ thực tế phụ thuộc bản in.
7. Ghép hai nửa đế bằng năm mộng, lắp hộp qua bốn tai tại X=21/129,
   Z=±45.5. Lắp chân màn hình và các board theo vị trí trong viewer.

## In và kiểm tra vật thật

STL chưa phải G-code. Kiểm tra preview lớp in và support/brim trong slicer:
trục tròn nằm ngang, bệ trục nhô khỏi thân, lỗ ngang và trụ chụp có vùng cần
xem xét hỗ trợ. Nắp đã úp mặt ngoài phẳng xuống bàn; khẩu độ nằm phẳng; ray D
úp mặt phẳng xuống bàn. Không có khẳng định toàn bộ bộ kit in được mà không support.

Khe CAD không bảo đảm kích thước sau co ngót. Kiểm tra tấm khẩu độ, một đoạn
trục và các lỗ trước khi in toàn bộ; làm sạch support và ba-via. Bản trục nhựa
cần đủ độ cứng và không cong; có thể dùng trục kim loại cùng kích thước.

Sau lắp, đo nền tối với khẩu độ bịt, kiểm tra khe nắp, bốn cửa dây, hai lỗ
trục ở d=15 và d=90. Mộng/rãnh ngăn đường sáng trực tiếp tại chỗ lắp, nhưng
khả năng đục quang của nhựa và mức rò sáng **chưa được đo bằng phần cứng**.

## Tái sinh và xác minh

Từ gốc repository, dùng môi trường CAD đã cài các phiên bản ghi trong
[requirements/cad.txt](../../requirements/cad.txt):

```bash
python3 -m venv .cad_venv
.cad_venv/bin/python -m pip install -r requirements/cad.txt
.cad_venv/bin/python docs/system_3d/build_system.py
.cad_venv/bin/python docs/system_3d/build_system.py --bambu
.cad_venv/bin/python docs/system_3d/verify_geometry.py
.cad_venv/bin/python docs/system_3d/render_fit_review.py
.cad_venv/bin/python docs/system_3d/render_preview.py
```

`build_system.py` sinh STL hệ lắp ráp, `out/model.json` và [viewer.html](viewer.html).
`--bambu` sinh bản simple và hai bàn in, giữ nguyên viewer đầy đủ. Các phép xoay
STL không cắt sửa hình học. `--detail simple --stl-only --only carrier` dùng
để dựng riêng chi tiết khi chỉnh. Bộ lắp linh kiện thật dùng scale=1.0; thay đổi
scale cũng làm đổi đường kính trục/lỗ/vít nên phải kiểm tra lại toàn bộ kích thước.

Mở viewer trực tiếp hoặc phục vụ thư mục `docs/system_3d` bằng HTTP.
Viewer chỉ hiển thị một khẩu độ mỗi làn; chọn tấm khác tự ẩn tấm trước đó.
Lịch sử các thiết kế v1–v3 nằm trong Git; báo cáo v4 thay cho kết quả 96 check cũ.

## Phụ lục — ước lượng quang học kế thừa

Mô hình điểm-xấp-xỉ-nghịch-bình-phương `V_out = Rv × Ie × (A/d²) + V_dark`:

**Kênh ĐỎ (622 nm — [ASSUME])** — LED yếu → để gần sensor:

| Vdac | I_LED | d=15 | d=25 | d=40 | d=60 | d=85 mm |
|---|---|---|---|---|---|---|
| 1.0 V | 5.0 mA | 1.457 | **0.529** | 0.211 | 0.098 | 0.053 V |
| 2.0 V | 10 mA | 2.907 | **1.051** | 0.415 | 0.189 | 0.098 V |

→ **d = 25 mm** khuyến nghị: dải Vdac 0.5–3.28 V đều dưới trần 2.13 V (không kẹp).

**Kênh IR (875 nm)** — LED rất mạnh → phải để xa để tránh bão hòa:

| Vdac | I_LED | d=25 | d=60 | d=85 mm |
|---|---|---|---|---|
| 1.0 V | 6.1 mA | 11.29 (⚠ kẹp) | 1.966 | **0.983** V |
| 2.0 V | 12.2 mA | 22.57 (⚠ kẹp) | 3.925 | **1.959** V |

→ **d = 85 mm** khuyến nghị: tại d=85 Vdac được phép tới 2.17 V; tại d=25 chỉ
0.19 V (gần như không điều khiển được). Đây là lý do hành trình trượt phải phủ
15–90 mm.

Các bảng kế thừa này không phải kết quả đo sau sửa cơ khí v4. Dòng LED trong bảng
phụ thuộc cấu hình driver/điện trở; hiệu chuẩn phải dùng thông số và phần cứng thực.

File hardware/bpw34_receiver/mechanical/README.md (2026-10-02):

# Gá chữ H cho bpw34_receiver 70 × 20 mm

In riêng `frame_70x20_bpw34_print.stl`, không in file `*_assembly.stl`. Không cần ốc.
Đặt PCB tựa trên thanh ngang; vùng phía dưới rỗng để luồn dây header. Rãnh hộp
4,3 mm, gá dày 3,8 mm, còn 0,5 mm danh nghĩa; nên in thử và lắp trượt vào hộp
thật trước khi in cả bộ. Mặt cảm biến hướng vào LED; bậc Y thế giới=23,7 mm,
mặt trước PCB X=137,5 mm, hai tâm quang Y=32 mm và Z=±19,25 mm.
Gá OPT101 và BPW34 khác độ cao bậc để giữ đúng trục quang.
Dùng băng keo cách điện đục quang cố định mép và bịt khe trên/vách giữa;
gá H tự nó không kín sáng. Cắt đuôi chân hàn không quá 2 mm.
`fit_report.json` và `optical_report.json` kiểm tra hình học danh nghĩa,
chưa thay cho thử lắp, đo chiều cao cảm biến và kiểm tra lọt sáng thực.

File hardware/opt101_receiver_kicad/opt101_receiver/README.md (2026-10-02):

> Gá mới: thanh chữ U không bắt vít, hai biến thể riêng theo receiver. Xem `mechanical/README.md`.

# PCB thu PPG — OPT101P ×2, 70 × 20 mm

Mở **`opt101_receiver.kicad_pro` bằng KiCad 10**, rồi mở schematic hoặc PCB.
Thiết kế đã đi dây hai lớp, có thư viện symbol, footprint và mô hình 3D cục bộ.
Ảnh `reports/pcb_top.png` hiển thị **socket trống**, chưa cắm IC OPT101P.
Mặt sau có silkscreen `DATN: PPG-Simulator` và
`Nguyen Nhat Huy - Pham Thanh Vy`; xem `reports/pcb_bottom.png`.
Mặt sau cũng ghi tên tín hiệu tại từng pad J1/J2/J3 và từng hàng chân của
hai socket OPT101. Các nhãn này không dùng số thứ tự chân; `R/I` là hai đầu
ra, `V` là 3,3 V, `GR/GI` là ground theo kênh, `FB` là hồi tiếp và `NC` để hở.

## Linh kiện và kết nối

| Ref | Linh kiện / quy cách | Số lượng |
|---|---|---:|
| U1, U2 | OPT101P dạng PDIP-8, cắm socket DIP-8 rộng 7,62 mm, bước chân 2,54 mm | 2 IC + 2 socket |
| C1, C2 | Tụ gốm dán **100 nF, 50 V, X7R, 0805**, không phân cực | 2 |
| R1, R2 | 1 kΩ 1%, SMD 0805, lọc ngõ ra | 2 |
| C3, C4 | 1 µF X7R 16 V, SMD 0805, không phân cực | 2 |
| J1, J2 | Header đực thẳng 1×4, bước 2,00 mm | 2 |
| J3 | Header đực thẳng 1×2, bước 2,54 mm | 1 |

Socket chỉ nhận **PDIP có chân xuyên lỗ**. OPT101 dạng SOP chân cong J không
cắm trực tiếp được. Đối chiếu package thực trước khi tháo IC khỏi module tím.
Rãnh socket và dấu pin 1 của IC hướng về cạnh trên có chữ RED/A2, IR/A0.

U1 là **Red → A2**, U2 là **IR → A0**. Với từng IC:

- Chân 1 → nguồn 3,3 V từ Grove; tụ 100 nF nối nguồn với GND ngay cạnh socket.
- Chân 3 và 8 → GND.
- Chân 4 nối trực tiếp chân 5 bằng đường đồng để dùng hồi tiếp 1 MΩ trong IC.
- Chân 2, 6, 7 để hở có chủ ý; không gắn điện trở 1 MΩ ngoài.

**J1/J2**, đọc theo số pad, từ pad vuông sang phải khi nhìn mặt linh kiện:

| Chân | J1 → socket A2 trên HAT | J2 → socket A0 trên HAT |
|---|---|---|
| 1 — SIG | OUT_RED | OUT_IR |
| 2 — NC | Không nối | Không nối |
| 3 — 3V3 | Nguồn 3,3 V | Nguồn 3,3 V |
| 4 — GND | GND | GND |

Pinout theo chuẩn Grove analog: pin 1 tín hiệu chính, pin 2 tín hiệu phụ,
pin 3 nguồn, pin 4 GND. Đây là **header trần bước 2 mm**, không phải socket
Grove có khóa. Kiểm tra thứ tự dây đến HAT trước khi cắm; không suy ra chiều
cắm chỉ từ màu dây. Chân phụ A1/A3 không được nối vào mạch.

C1/C2 là tụ bypass nguồn, **không phân cực**. Điện áp mạch chỉ 3,3 V nhưng
chọn loại 50 V X7R cỡ 0805. Loại 25 V X7R cỡ 0805 cũng dùng được về điện;
không thay bằng tụ điện phân vì tác dụng bypass cao tần khác nhau.

Mỗi kênh có đường nguồn và vùng GND riêng trên PCB; hai GND chung tại HAT.
Cắm cả hai cáp Grove để cấp nguồn đủ hai kênh. Không cấp 5 V vào board.

**J3 cho ADS1115**:

| Chân | Tín hiệu | Cách nối dự kiến |
|---|---|---|
| 1 — pad vuông, RED | OUT_RED, sau R1, cùng net J1.1 | ADS1115 AIN0 |
| 2 — IR | OUT_IR, sau R2, cùng net J2.1 | ADS1115 AIN1 |

J3 là ngõ lấy tín hiệu song song, không có buffer, không có nguồn hoặc GND.
ADS1115 cần được cấp nguồn riêng phù hợp và **nối GND về cùng GND HAT/Pi**.
Việc cấp nguồn OPT101 vẫn qua J1/J2. Hai đầu ra không phải một cặp vi sai:
đọc từng kênh so với GND. Cấu hình ADC, I²C và phần mềm ADS1115 chưa thuộc
thiết kế này. Nên dùng dây tín hiệu ngắn, đi sát dây GND; tải của ADC/cáp và
việc đọc đồng thời với Grove chưa được thử trên phần cứng.

## Kích thước và khớp mô hình 3D

PCB v1.5: **70 × 20 × 1,6 mm**, không có lỗ bắt vít. Tính từ góc trên trái:
- Tâm OPT101: (15,75; 7,81) và (54,25; 7,81) mm.
- J1/J2: chân đầu tại X=13/51 mm, Y=16,5 mm; bước 2 mm.
- J3: X=26/28,54 mm, Y=16,5 mm.

Đường đồng ngang/dọc; R1/R2 và C3/C4 ở mặt sau, C1/C2 sát socket ở mặt trước.
Gá riêng `mechanical/frame_70x20_print.stl` giữ mặt PCB tại X thế giới 137,5 mm,
bậc đỡ Y=19,81 mm; tâm quang vẫn Y=32 mm, Z=±19,25 mm. Hai kênh cách 38,5 mm.
Gá không bắt vít; giữ board và bịt khe/vách giữa bằng băng keo cách điện đục quang.
Không dùng gá BPW34 thay gá OPT101 vì vị trí cảm biến theo cạnh ngắn khác nhau.

### Kiểm tra đường ánh sáng và khẩu độ

Kiểm tra boolean dùng trực tiếp STL thân hộp, nắp, các tấm khẩu độ và khung PCB
mới đạt **20/20 phép thử hình học**. Ở vị trí danh nghĩa, trục của LED Red và
IR đều đi qua tâm lỗ khẩu độ tại X = 114,2 mm rồi đến tâm vùng nhạy của OPT101
tương ứng. Tia thẳng từ LED này hướng tới cảm biến kia cắt vách ngăn đặc giữa
hai buồng, nên không có đường nhìn thẳng xuyên kênh.

- Tấm `blank` chặn tia trục của cả hai kênh.
- Lỗ Ø2, Ø5 và Ø16 đều cho tia trục đi qua.
- Vùng nhạy OPT101 là 2,29 × 2,29 mm. Khi chiếu ngược các góc vùng nhạy lên
  mặt khẩu độ, bán kính góc lớn nhất là khoảng 0,99 mm cho Red và 1,40 mm cho
  IR. Vì vậy Ø2 chỉ vừa đủ cho Red và cắt các góc vùng nhạy IR; **Ø5 hoặc Ø16
  phủ toàn bộ vùng nhạy danh nghĩa của cả hai kênh**.
- Bán kính chùm tại mức nửa cường độ trong mô hình nguồn lớn hơn các lỗ khẩu
  độ, nên khẩu độ chủ động giới hạn lượng sáng. Kiểm tra này xác nhận đường
  nhìn và độ phủ hình học, không dự đoán công suất quang hoặc biên độ tín hiệu.

Kết luận phụ thuộc vào tâm package danh nghĩa và khoảng X cửa sổ cảm biến
126,5–132,0 mm lấy từ bao socket + IC. Sai số tâm die, chiều cao socket thật,
độ trong của nhựa in, phản xạ mặt trong và khe lắp chưa được mô phỏng. Sau khi
in cần thử lần lượt với tấm `blank` và Ø5: `blank` phải cho mức tối gần như nhau
khi LED bật/tắt, còn Ø5 phải tạo đáp ứng rõ chỉ ở đúng kênh.

### Thay đổi mốc khoảng cách quang

Mô hình cũ đặt cửa sổ module tại X = 120 mm nhờ module tím và trụ đỡ.
Cắm IC trực tiếp lên socket của PCB **không giữ nguyên mốc 120 mm**.
Gọi `h` là khoảng cách đo vuông góc từ mặt linh kiện PCB đến cửa sổ quang
của IC đã cắm hết vào socket:

```
X_cửa_sổ_mới = 137,5 - h
d_thực = d_theo_thang_cũ + 17,5 - h
```

Ví dụ **chỉ để minh họa**, nếu đo h = 8,3 mm thì d thực tăng 9,2 mm.
Không dùng ví dụ này như kích thước bảo đảm của socket. Mã mô hình cũ và
thang khoảng cách cũ chưa được đổi; phải đo lại h và hiệu chuẩn khoảng cách.
Không đưa board ra trước để cố giữ X=120 vì board liền sẽ đụng vách ngăn giữa.

## Kiểm tra và giới hạn

Kiểm tra bằng **KiCad 10.0.6**: ERC 0 lỗi/0 cảnh báo; DRC 0 vi phạm,
0 pad chưa nối, 0 lỗi parity; 152 kiểm tra hợp đồng chân, kích thước,
hình học đường đồng đạt.
Kiểm tra cơ khí: 386/386 đạt với bao linh kiện đã nêu; khung là một khối kín.
Kiểm tra đường quang danh nghĩa: 20/20 đạt.

- `reports/erc.rpt`: ERC schematic.
- `reports/drc.rpt`: DRC, vùng đồng đã đổ, kiểm tra parity với schematic.
- `reports/pin_contract.json`: kiểm tra độc lập chân điện, bước header/socket,
  kích thước board và khoảng cách hai làn.
- `mechanical/fit_report.json`: kiểm tra boolean với **STL thân/nắp đã xuất
  trong source**, gồm đường đưa cụm từ trên xuống theo bước 2 mm.
- `mechanical/optical_report.json`: kết quả định lượng đường tia, độ che của
  từng khẩu độ và chặn tia chéo giữa hai kênh.
- `mechanical/optical_alignment.png`: hình diễn giải vị trí LED, khẩu độ và
  khoảng cửa sổ OPT101 theo trục X.

Kiểm tra cơ khí dùng bao linh kiện: socket + IC cao tối đa 11 mm, header
cao tối đa 12 mm, tụ cao tối đa 7 mm phía trước PCB. Chọn linh kiện trong
các bao này. Đầu cáp mềm chưa được mô hình hóa. Kiểm tra CAD không thay thế
thử lắp bản in, kiểm tra rò sáng, đo điện hoặc hiệu chuẩn quang thực tế.

Các kết quả phần cứng chưa thực hiện: nguồn thật, cắm socket, mức tín hiệu,
nhiễu, bão hòa, Grove ADC và ADS1115. ERC/DRC sạch không phải chứng minh
đã đo được tín hiệu PPG trên mạch thật.

## File gia công

`fabrication/` chứa Gerber hai lớp đồng, soldermask hai mặt, silkscreen và
Edge.Cuts, kèm Excellon tách PTH/NPTH. Số lượng/cỡ lỗ khoan theo `reports/drill.rpt`; receiver không còn lỗ bắt vít. Chọn FR4 dày 1,6 mm,
đồng 1 oz, 70 × 20 mm; không yêu cầu trở kháng kiểm soát.
File này đã xuất nhưng **chưa được gửi đặt sản xuất**. Kiểm tra package IC,
socket, đầu cáp và bản in khung thật trước khi chốt gia công.

## Tái sinh

Không cần chạy script để mở hoặc chỉnh file trong KiCad. `generate_design.py`
**ghi đè** thiết kế đã sinh; chỉ chạy lại nếu muốn tái tạo từ mã tham số.

```bash
python-with-pcbnew generate_design.py --kicad-share /path/to/share/kicad --cli /path/to/kicad-cli
kicad-cli sch erc opt101_receiver.kicad_sch -o reports/erc.rpt
kicad-cli pcb drc opt101_receiver.kicad_pcb --refill-zones --save-board --schematic-parity -o reports/drc.rpt
python-with-pcbnew verify_design.py
# Từ gốc repository:
.cad_venv/bin/python hardware/opt101_receiver_kicad/opt101_receiver/mechanical/build_adapter.py
.cad_venv/bin/python hardware/opt101_receiver_kicad/opt101_receiver/mechanical/optical_check.py
```

Nguồn kỹ thuật:

- [TI OPT101 datasheet, pinout và hồi tiếp](https://www.ti.com/lit/ds/symlink/opt101.pdf), trang 3, 13 và 23.
- [Seeed Grove System](https://wiki.seeedstudio.com/Grove_System/), pinout Grove analog.
- [Grove Base HAT for Raspberry Pi](https://wiki.seeedstudio.com/Grove_Base_Hat_for_Raspberry_Pi/), analog 3,3 V.
- Sơ đồ gốc: `docs/hardware/PPG_PROTOTYPE_SCHEMATIC.md`, phần RX.

Footprint và mô hình 3D được sao chép từ thư viện KiCad 10, đổi tên thư viện
thành PPG và dùng đường dẫn tương đối để dự án có thể chuyển máy.
Thư viện KiCad dùng CC-BY-SA 4.0 với ngoại lệ sử dụng trong thiết kế điện tử:
[KiCad Library License](https://www.kicad.org/libraries/license/).

## Schematic v1.5 — lọc ngõ ra

Hai kênh được vẽ bằng dây nối trực tiếp từ Grove qua nguồn/bypass tới OPT101,
strap 4–5, rồi qua R1/R2 = 1 kΩ tới Grove/J3; C3/C4 = 1 µF nối từ OUT sau điện trở xuống GND từng kênh. Bộ lọc có fc danh nghĩa 159 Hz, suy hao khoảng 0,8% tại 20 Hz; không phải lọc notch 50 Hz. Với nguồn 3,3 V, OPT101 không rail-to-rail: cần chừa headroom khoảng 1,15–1,3 V phía nguồn dương. Xem `reports/schematic.pdf` và `reports/schematic.png`. Giao cắt không
có dấu chấm không nối điện.

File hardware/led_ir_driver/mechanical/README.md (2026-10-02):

# Adapter driver 70 × 40 mm

In `driver_70x40_adapter_print.stl`: bao 70 × 55 × 6 mm, gắn vào đế cũ tại X=4/66, Y=4/51 mm.
PCB đặt tại (0;7;6) mm trên adapter. Bốn lỗ PCB local X=4/66,Y=24/36 mm
khớp bốn lỗ mồi Ø2,6 mm ở Y=31/43 trên adapter; dùng vít ngắn phù hợp nhựa.
C7 mặt sau nằm trên cửa rỗng giữa adapter. Kiểm tra chiều cao tụ/module thật,
chiều dài vít và cáp trước lắp. Báo cáo chỉ xác nhận hình học danh nghĩa;
chưa thử in/lắp thực.

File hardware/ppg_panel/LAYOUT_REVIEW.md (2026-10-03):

# Rà soát layout và V-score — 2026-10-03

## Rà soát toàn bộ ba board và panel

Đã đi lại các đường vòng bằng các tuyến ngang/dọc/chéo 45° ít đoạn hơn,
thay vì chỉ vát từng góc của đường cũ. Đã bỏ đồng trùng, phần nhô dư ở
SENSE_RED và các via không còn dùng sau khi đổi tuyến. Các điểm nối thật
ở pad, via và nhánh điện được giữ; ảnh wiring hiện đánh dấu cả via hai lớp.

| Board | Số đoạn đồng trước → sau | Tổng chiều dài trước → sau |
|---|---:|---:|
| OPT101 | 57 → 37 | 163,76 → 129,69 mm |
| BPW34 | 203 → 133 | 381,89 → 312,16 mm |
| LED/IR driver | 200 → 98 | 488,13 → 415,25 mm |

OPT101: rút gọn nguồn, đường raw và đường output tới header.
BPW34: bỏ vòng nguồn sát biên, rút gọn SUM/feedback và bỏ hai via nguồn dư.
Driver: đi lại I²C, DAC, base transistor, cathode LED và các đường hồi tiếp;
bỏ vòng dây và phần đồng dư quanh LM358. Các đường vòng còn lại tránh pad
khác net hoặc giữ kết nối ở hai lớp; không đánh đổi khoảng hở để giảm số đoạn.

Ba nguồn: DRC không có vi phạm hoặc thiếu kết nối; PCB khớp schematic.
Panel: DRC sạch, 566 kiểm tra nguồn/panel và V-cut đạt. Kiểm tra hình học
không còn đoạn đồng trùng hoặc góc rẽ tự do 90°. Giá trị linh kiện, chân/net,
footprint, vị trí, hướng và kích thước board không đổi.
Chi tiết trước/sau nằm trong `reports/miniaturization_audit.json`.

## Đi dây và bố trí hai mặt

Ba board dùng đoạn ngang/dọc và đoạn chéo 45°, vát các góc rẽ tự do 90°.
Độ lùi vát góc danh nghĩa tăng từ 0,4 lên 1,2 mm để đoạn chéo rõ nét,
không dùng cung tròn. Góc trong vùng chật được giới hạn bởi chiều dài đoạn
và vị trí nhánh nối; không kéo đoạn chéo qua điểm đáp của nhánh.
Điểm vào pad, via và điểm phân nhánh điện được giữ để không cắt mất kết nối.
Không đổi net, giá trị linh kiện, vị trí header, tâm cảm biến
hay kích thước board. `hardware/routing_45.py --audit` kiểm tra góc đoạn dây
và góc rẽ; DRC/parity kiểm tra kết nối và khoảng hở thực tế.

Góp ý đặt linh kiện hai mặt có ích khi giải quyết được đường dây hoặc diện tích.
Không có quy tắc bắt buộc tất cả điện trở ở dưới, tụ ở trên:

- OPT101 đã có C1/C2 mặt trước; điện trở và tụ lọc output mặt sau. Giữ cách này.
- BPW34 giữ op-amp, Rf và Cf cùng mặt sau để vòng SUM/feedback ngắn, tránh thêm
  via vào nút trở kháng cao. Mặt trước dành cho photodiode và không gian gá.
  Tụ bypass và tụ reference nằm gần mạch analog tương ứng.
- Driver giữ điện trở gần LM358/transistor; tụ 100 nF gần chân nguồn,
  tụ bulk phía sau. Đổi mặt chỉ để phân loại R/C không làm giảm khung 70×40 mm,
  trong khi có thể thêm via, kéo dài đường hồi tiếp và tăng chi phí lắp hai mặt.

Góc 90° không tự làm đường đồng đứt. Rủi ro khi tách board là đồng/linh kiện
quá gần đường cắt và ứng suất uốn; chuyển góc rẽ 45° giúp layout đồng đều,
không thay thế kiểm tra DRC, khoảng hở và quy trình tách.

## Đối chiếu video và điều kiện gia công

Đã đọc transcript và xem minh họa [video DIY Hideout](https://www.youtube.com/watch?v=ph2jV5HMxfQ):
đường bao ngoài là Edge.Cuts, đường V-score là chỉ dẫn riêng và cần xuất Gerber
của lớp chỉ dẫn. Ví dụ thủ công thêm 2 mm khoảng đệm; không áp dụng con số đó
như quy định bắt buộc cho mọi nhà in. Không bỏ qua lỗi kết nối như mẹo trong
ví dụ nhân bản board: panel này dùng tiền tố net riêng cho từng thiết kế.

[Hướng dẫn NextPCB](https://www.nextpcb.com/blog/pcb-panelization-design-guide-v-score-tab-routing)
cho phép V-score ghép không khe, cùng vật liệu/stack-up, và khuyến nghị linh kiện
cách V-cut ít nhất 1 mm. Panel hiện tại:

- FR-4 1,6 mm, hai lớp đồng; khung chữ nhật 70×80 mm.
- Hai tâm V-score Y=20/40 mm từ cạnh trên, chạy hết chiều ngang 70 mm.
- Chỉ phay đường bao ngoài; không phay khe ở tâm V-score.
- Đồng/pad/via/vùng đồng cách tâm score ≥1,5 mm mỗi phía.
- Bao footprint R/C cách tâm score ≥2,095 mm; không có nối điện giữa ba board.

Các điều kiện hình học này phù hợp V-score danh nghĩa. Dấu vẽ trong KiCad không
tự tạo rãnh cơ khí: nhà in phải **score hai mặt**, xác nhận độ sâu, phần FR-4
còn lại và dung sai theo máy của họ. Tách bằng dụng cụ V-score **trước khi hàn**,
đặc biệt tránh uốn panel đã lắp tụ gốm. Không dùng lực bẻ mạnh để thay cho score
đúng độ sâu. Nếu nhà in lắp SMT theo panel, họ cần duyệt thanh biên/fiducial
và phương án tách riêng; bản này là panel PCB trần, không mặc định là panel SMT.

## Kết quả và giới hạn

Ba nguồn: DRC/parity sạch; kiểm tra pin/value và SMD vẫn đạt.
Panel: DRC sạch và đối chiếu nguồn, net riêng, lỗ khoan, vùng V-score đạt.
Xem `reports/drc.rpt`, `reports/panel_audit.json` và báo cáo của từng nguồn.
Đây là kiểm tra CAD; chưa chứng minh nhiễu, độ ổn định analog hay khả năng
tách một mẫu sản xuất thực. Nhà in phải duyệt CAM trước khi sản xuất.

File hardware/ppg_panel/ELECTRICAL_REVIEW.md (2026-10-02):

# Rà soát ba board — 2026-10-02

Không phát hiện lỗi chập nguồn, đảo net hoặc đứt mạch trong CAD đã kiểm tra.
Cả bản đầu vào và bản sửa đều được chạy ERC/DRC; bản cuối được kiểm tra
schematic–PCB và tập chân/net độc lập. Đây là thiết kế để làm mẫu thử;
chưa có phép đo điện/dao động/nhiễu trên ba PCB này đã lắp thực tế.

## Đường nguồn và lỗ khoan

| Board | Đường nguồn thực | Tải dự kiến | Đánh giá |
|---|---|---|---|
| OPT101 | 0,50 mm tuyến chính; 0,35 mm nhánh ngắn vào IC/tụ | IC khoảng 0,12–0,22 mA điển hình mỗi kênh, cộng tải OUT | Dư cho tải thiết kế |
| BPW34 | 0,40 mm tuyến chính; 0,35 mm nhánh | OPA333 khoảng 17 µA điển hình, cầu chia 30 µA, cộng tải OUT | Dư cho tải thiết kế |
| LED/IR driver | 5 V: 0,60–0,80 mm; 3,3 V: 0,60 mm; cathode/emitter dòng LED: 0,60 mm | Hai LED khoảng 16,5 mA/kênh, cộng LM358 | Dư cho tải thiết kế |

Tính kiểm tra sụt áp với đồng danh nghĩa 35 µm, điện trở suất 1,724×10⁻⁸ Ωm:
đoạn rộng 0,60 mm dài 100 mm có R≈0,082 Ω, sụt khoảng 4,1 mV ở 50 mA.
Đoạn 0,35 mm cùng chiều dài có R≈0,141 Ω, sụt 0,141 mV ở 1 mA.
Đây là mô hình DC có ghi giả thiết, không phải chứng chỉ dòng tối đa theo IPC.
Các nhánh hồi tiếp 0,22/0,35 mm mang dòng tín hiệu rất nhỏ; không cần làm
rộng chúng như nhánh công suất. GND có vùng đồng và các thermal spokes.
Không tăng dòng LED hàng trăm mA chỉ dựa trên kết quả bề rộng này.

Hai receiver không còn lỗ bắt vít; driver giữ bốn lỗ M3. Kiểm tra panel đo
khoảng cách đồng tới lỗ và đường V-cut, xem `reports/panel_audit.json`.
Không có track xuyên lỗ khoan hoặc đường cắt. Dwgs.User là chỉ dẫn vách quang,
không phải khe phay. Toàn bộ track trên cả ba nguồn đi ngang/dọc.

## Tín hiệu thu và mạng lọc mới

Mỗi kênh nay là `OUT tầng khuếch đại → R 1kΩ → OUT tới Grove/ADS`, với
tụ **1µF X7R, không phân cực, ≥16 V, 0805** từ OUT sau điện trở về GND
của chính kênh. OPT101 thêm R1/R2, C3/C4. BPW34 đổi R3/R4 từ 100 Ω lên
1 kΩ và thêm C7/C8. C1/C2 100 nF của OPT101 vẫn là bypass nguồn;
C1/C2 22 pF C0G của BPW34 vẫn nằm song song điện trở hồi tiếp 1 MΩ.
Không nhầm tụ ổn định TIA với tụ lọc OUT; không mắc trực tiếp 1 µF vào
đầu ra IC trước điện trở cách ly.

Với tải ADC đủ lớn: fc=1/(2πRC)=159,15 Hz, hằng số thời gian 1 ms.
Biên độ tương đối ở 10/20/50/100/1000 Hz lần lượt khoảng
99,80% / 99,22% / 95,40% / 84,67% / 15,72%; pha ở 20 Hz khoảng −7,16°.
Lựa chọn này giữ phần lớn thành phần PPG đến 20 Hz, đồng thời giảm nhiễu
cao tần và tách tải cáp/ADC khỏi vòng hồi tiếp. Đây là giá trị thử có cơ sở,
chưa phải tối ưu SNR đã đo. Không đủ để khử mạnh 50 Hz hoặc làm bộ chống
alias hoàn chỉnh cho mọi tốc độ lấy mẫu. Nếu cần băng thông khác phải tính
lại theo dạng sóng và tốc độ ADC thực, không tự tăng tụ cho “sạch hơn”.

Tụ X7R có sai số và suy giảm điện dung theo điện áp DC: dùng cùng mã linh
kiện cho hai kênh, kiểm tra đường cong nhà sản xuất, đo/hiệu chuẩn biên độ
và pha nếu cần so sánh RED/IR chính xác. Tụ 16/25/50 V phù hợp điện áp,
miễn đúng footprint và điện dung hiệu dụng. Có thể để trống tụ OUT để A/B
test; vẫn giữ điện trở 1 kΩ. Nếu ADC ở xa, đặt lọc phù hợp ngay đầu ADC
và đi dây OUT sát dây GND. Hai ADC đọc song song tạo tải chung, chưa đo thực.

## Giới hạn cần biết trước khi dùng

1. **OPT101 không rail-to-rail.** Với VS=3,3 V, bảng thông số cho đầu ra cao
   khoảng VS−1,15 V điển hình và VS−1,3 V ở giới hạn được nêu, tức khoảng
   2,15/2,0 V theo điều kiện datasheet. Có thể clipping trước khi ADC chạm
   3,3 V. Giảm ánh sáng/dòng LED hoặc đổi gain đúng topology; RC không sửa
   được clipping. Chân 4–5 vẫn nối trực tiếp, dùng 1 MΩ nội; chân 2/6/7 để hở.
2. **BPW34:** cathode vào ngõ đảo OPA333; anode về GND. VREF≈0,30 V;
   VOUT≈0,30 V+Iphotodiode×1 MΩ. Dòng quang cỡ vài µA đã có thể làm bão hòa.
   Hồi tiếp âm và pin SOT-23-5 đã đối chiếu. 22 pF giúp bù điện dung diode;
   độ ổn định thực, leakage bề mặt và nhiễu cần đo. Giữ sạch flux quanh SUM.
3. **Driver:** LM358.8=5 V, .4=GND; 2N4401 theo onsemi là E-B-C, không
   thay C1815 trực tiếp. R4/R9=100 Ω, cầu chia DAC 1/2 cho dòng emitter
   tối đa danh nghĩa 16,5 mA, công suất sense≈27,2 mW <250 mW.
   Dòng LED thấp hơn một chút do dòng base. C2/C4 vẫn DNP: phải đo vòng
   điều khiển trước khi chọn tụ bù. Chưa chứng minh không overshoot/dao động.
4. Hai GND trên MCP4725 cùng mốc 0 V: nối chúng là đúng, không phải ngắn
   OUT hoặc VCC. Hai OUT DAC tách riêng. IR/RED cần địa chỉ 0x60/0x61 trên
   jumper thật của module. Carrier không tự đặt địa chỉ. Kiểm tra tổng
   pull-up I²C của Pi/HAT/hai module; không thêm pull-up trên carrier.
5. MCP4725 nạp EEPROM khi bật nguồn, driver chưa có khóa tắt LED độc lập.
   LED có thể sáng trước lệnh DAC=0. Nguồn 5 V driver và Pi cần chung GND,
   nhưng không cho dòng hồi LED đi xuyên dây GND board thu.
6. J3 OPT101 vẫn chỉ có RED/IR: ADS1115 **phải có dây GND chung với HAT/Pi**;
   cắm riêng hai dây OUT vào một ADC không có GND chung là sai. J3 BPW34
   có RED/GND_RED/IR/GND_IR. Không nối song song hai tín hiệu RED và IR.

Ba PCB hiện tại: 70×20, 70×20 và 70×40 mm; tổng 56 cm², giảm 25,93%
so với 75,6 cm² của bản trước. Giữ nguyên net, giá trị linh kiện và trục quang;
chỉ bỏ lỗ/gá vít của receiver, dời linh kiện và đổi đường đi đồng.
Hai receiver dùng hai thanh U khác bậc đỡ; driver dùng adapter mới.
Chưa đo kích thước module MCP4725 và chưa thử in/lắp thực.

## Nguồn kỹ thuật

- [TI OPT101](https://www.ti.com/lit/ds/symlink/opt101.pdf): hồi tiếp, biên độ OUT, bypass và tải điện dung.
- [TI OPA333](https://www.ti.com/lit/ds/symlink/opa333.pdf), [Vishay BPW34](https://www.vishay.com/docs/81521/bpw34.pdf): pinout, dòng tĩnh và đặc tính diode.
- [TI ADS1115](https://www.ti.com/lit/ds/symlink/ads1115.pdf): tải đầu vào và lọc RC; dải PGA không cho phép quá áp nguồn.
- [TI LM358](https://www.ti.com/lit/ds/symlink/lm358.pdf), [onsemi 2N4401](https://www.onsemi.com/pdf/datasheet/2n4401-d.pdf).
- [Microchip MCP4725](https://ww1.microchip.com/downloads/aemDocuments/documents/MSLD/ProductDocuments/DataSheets/MCP4725-Data-Sheet-20002039E.pdf).
- [JLCPCB panelization](https://jlcpcb.com/help/article/pcb-panelization): V-cut thẳng hết panel, zero-gap, phí nhiều thiết kế.

## Vùng đồng và khoảng hở V-cut cập nhật

Driver có hai vùng đồng /GND trên F.Cu và B.Cu. F.Cu thường hiển thị đỏ: màu chỉ lớp đồng, không biểu thị nguồn dương. Các pad/track 5V, 3V3, OUT/SCL/SDA vẫn tách khỏi GND theo clearance; DRC kiểm tra chập và kết nối.
Đồng panel cách đường V-cut ít nhất 1,5 mm, bao footprint R/C ít nhất 2 mm. Không bảo đảm tụ gốm chịu được lực bẻ sau khi hàn: tách PCB trần trước khi lắp, dùng dụng cụ hạn chế lực uốn.

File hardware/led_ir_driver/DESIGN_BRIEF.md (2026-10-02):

> Ghi chú lịch sử yêu cầu ban đầu. Kích thước gia công mới là 70 × 40 mm; dùng README.md và mechanical/README.md cho revision v1.9.

# LED / IR driver — thiết kế đang triển khai

Pinout đã được người dùng xác nhận bằng ảnh: từ trên xuống
OUT / GND / SCL / SDA / VCC / GND. Một header đực J2 nhận bus/nguồn Pi;
hai socket module dùng chung GND, 3,3 V, SCL và SDA.

## Phần đã xác định

- Hai MCP4725 dạng module, cắm hai socket cái 1×6 bước 2,54 mm.
- J2 gồm header đực 1×2 2,54 mm (OUT/GND) và 1×4 2,00 mm (SCL/SDA/3V3/GND) cho dây Pi. J4 là header đực OUT_RED/GND 1×2 bước 2,54 mm.
- LM358P dùng socket DIP-8, khoảng cách hai hàng 7,62 mm.
- Q1/Q2 chọn 2N4401 TO-92 theo datasheet onsemi, chân 1 E, 2 B, 3 C.
  Không cắm C1815 vào cùng footprint: thứ tự E/C/B khác nhau.
- MCP4725 dùng nguồn 3,3 V và bus I²C 3,3 V; LM358 và anode LED dùng 5 V.
- IR địa chỉ 0x60, Red 0x61, cấu hình địa chỉ trên module.
- Mỗi DAC qua cầu chia 10 kΩ / 10 kΩ 1% đến ngõ vào không đảo LM358.
- IR: LM358 chân 1 OUT, 2 feedback, 3 command; Red: 7 OUT, 6 feedback,
  5 command. LM358 chân 4 GND, chân 8 +5 V.
- Điện trở base 1 kΩ; sense IR 100 Ω 1%, Red 100 Ω 1%, công suất 0,25 W.
- Dòng emitter xấp xỉ VDAC/(2 Rsense): tại 3,28 V là 16,40 mA IR và
  16,40 mA Red; tại 3,30 V là 16,50 mA và 16,50 mA. Dòng LED collector
  nhỏ hơn dòng emitter bởi dòng base; không coi các số này là dòng đã đo.
- Tụ bypass LM358 C5 100 nF; đầu nguồn 5 V có C7 10 µF.
- Chỉ giữ hai vị trí bù vòng C2/C4 (DNP). Bỏ C1/C3, C6, R5/R10 để
  giảm linh kiện/vị trí dự phòng chưa có yêu cầu đo. Xem COMPONENT_RATIONALE.md.
- Khổ cơ khí tham chiếu từ mô hình driver hiện có: 70 × 55 mm,
  tâm bốn lỗ cách mép 4 mm. Đây là board driver, khác board RX 70 × 32 mm.
- B.Silkscreen: `DATN: PPG-Simulator` và
  `Nguyen Nhat Huy - Pham Thanh Vy`.

## Module tham chiếu

Ảnh `docs/system_3d/assets/mcp4725_raw.jpg` thể hiện hàng chân
GND / VCC / SDA / SCL / GND / OUT. Không suy ra rằng mọi module MCP4725
đều cùng thứ tự. Ảnh người dùng cung cấp đã xác nhận thứ tự cho bản PCB này.
Mô hình cũ mô tả kích thước module là giả định, chưa đủ xác nhận cơ khí.

## Chọn transistor

2N4401 onsemi có giới hạn dòng collector 600 mA và VCEO 40 V;
C1815 Toshiba trong source có giới hạn 150 mA và 50 V. Cả hai dư khả năng
về dòng/áp cho ứng dụng này. Chọn 2N4401 cho bản mới để thống nhất BOM
và footprint; không coi dòng tối đa lớn hơn là bằng chứng chính xác hơn.
Độ chính xác vẫn phụ thuộc điện trở sense, DAC, LM358, nhiệt và dòng base.

Nguồn: https://www.onsemi.com/pdf/datasheet/2n4401-d.pdf;
`docs/ds_linhkien/2SC1815L-GR.PDF`;
`docs/hardware/PPG_PROTOTYPE_SCHEMATIC.md`.

Chưa xác nhận thực nghiệm: dòng LED, độ ổn định vòng điều khiển, trạng thái
LED khi DAC khởi động/nạp EEPROM, module thực và lắp vừa đế in.

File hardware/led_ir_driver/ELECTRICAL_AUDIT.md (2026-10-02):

# Kiểm tra điện LED/IR driver v1.6 — 2026-09-29

## Kết luận và phạm vi

Không phát hiện lỗi nối điện trong schematic/netlist và PCB hiện tại. Hai
GND trên mỗi module được nối chung có chủ đích; OUT không nối tắt xuống GND.
Các phần tử trong vòng điều khiển dòng có đúng pinout và chiều hồi tiếp âm.
Kiểm tra CAD đạt; chưa kiểm tra board lắp thật, địa chỉ chip thật, dao động,
quá độ bật nguồn hoặc kích thước cơ khí của hai module mua thực tế.

V1.6 giữ nguyên 17 tập chân/net và 92 đoạn đồng so với bản v1.5 trên đĩa
trước rà soát. Sửa schematic để đường bus không xuyên thân connector; nhãn
giống nhau vẫn là cùng một net điện. Thêm ADDR=GND / ADDR=VCC lên PCB và
sửa tài liệu/bộ file xuất. Không thay đổi giá trị linh kiện hoặc pitch.

## GND cạnh OUT có phải một tín hiệu khác?

Không. Module có một chân OUT và hai chân GND để tiện đưa nguồn/bus và
lấy tín hiệu analog bằng hai nhóm dây. Cả hai GND cùng mốc 0 V; điện áp
OUT được đo so với mốc này. Trên carrier, pin 2 và 6 của J1/J3 cùng về
vùng đồng B.Cu, chung với J2.2/J2.6, J4.2, J7.2 và LM358.4.

| Net | Toàn bộ chân liên quan ở nhóm module/header |
|---|---|
| OUT IR | J1.1, J2.1, R1.1 |
| OUT RED | J3.1, J4.1, R6.1 |
| GND | J1.2/6, J2.2/6, J3.2/6, J4.2; nối về GND nguồn và analog |
| SCL | J1.3, J2.3, J3.3 |
| SDA | J1.4, J2.4, J3.4 |
| 3V3 | J1.5, J2.5, J3.5 |

Nối GND–GND không gây chập nguồn. Nối OUT–GND, VCC–GND hoặc hai OUT với
nhau mới sai. Hai kênh dùng chung nguồn/bus nhưng có DAC_OUT, command,
base, sense và cathode LED riêng biệt.

## Địa chỉ I²C và cấu hình module

- Với phiên bản MCP4725A0, A0/ADDR thấp cho địa chỉ 7-bit 0x60, cao cho
  0x61. IR chọn GND; RED chọn VCC=3,3 V trên jumper của chính module.
- Carrier không tiếp cận ADDR vì hàng sáu chân không có chân này. Chữ
  0x60/0x61 trên PCB chỉ là hướng dẫn lắp, không tự đổi địa chỉ chip.
- Nếu có cầu hàn trực tiếp ADDR–GND, gỡ cầu đó trước khi hàn ADDR–VCC.
  Không hàn nối cả ba pad. Điện trở kéo xuống ADDR 10 kΩ, nếu có, không
  đồng nghĩa với một cầu hàn ngắn mạch. Giữ hai chân GND luôn về GND.
- Hai module cùng địa chỉ thường chỉ xuất hiện tại một ô khi quét và cùng
  nhận lệnh ghi. Việc trùng địa chỉ không tự gây cháy mạch, nhưng không thể
  điều khiển hai kênh độc lập. GND chung không quyết định địa chỉ.
- A2/A1 của MCP4725 được cấu hình tại nhà máy. Nếu module mua dùng biến thể
  khác, quét riêng từng module để xác nhận thay vì suy ra từ màu PCB.
- Chỉ cấp 3,3 V cho module và bus Pi. Nguồn J7=5 V cấp LM358/LED; hai rail
  nguồn không nối chung. Một cáp bốn lõi vào J2.3–6 cấp bus cho cả hai DAC.

Module trong ảnh có các điện trở ghi 472 (4,7 kΩ); cần đối chiếu mạch thật
trước khi sửa jumper. GPIO2/3 của Pi đã có pull-up cố định. Các pull-up
trên hai module và HAT mắc song song; carrier không lắp thêm điện trở kéo
lên. Ví dụ giả định Pi có 1,8 kΩ và hai module đều 4,7 kΩ: tổng khoảng
1,02 kΩ. Nếu còn một nhánh 4,7 kΩ khác thì còn 0,84 kΩ, cần khoảng
3,46 mA để giữ mức thấp 0,4 V ở rail 3,3 V, vượt điều kiện 3 mA trong
datasheet MCP4725. Đây là ví dụ tính tải, chưa phải phép đo HAT của bạn.
Khi lắp, kiểm tra tổng pull-up và dạng xung; ngắt bớt pull-up trên module
nếu cần, giữ pull-up phù hợp về 3,3 V của Pi/HAT. Không tháo nhầm điện trở
ADDR. Không thể vô hiệu hóa pull-up nằm trên module chỉ bằng sửa carrier.

## Đối chiếu linh kiện và dòng điện

| Khối | Kết nối được kiểm tra | Vai trò |
|---|---|---|
| U1 nguồn | 8→5 V; 4→GND | Đúng LM358 DIP-8 |
| U1A IR | 3→CMD_IR; 2→R4.1/Q1.E; 1→R3 | Hồi tiếp âm kênh IR |
| U1B RED | 5→CMD_RED; 6→R9.1/Q2.E; 7→R8 | Hồi tiếp âm kênh RED |
| R1/R2, R6/R7 | 10 kΩ/10 kΩ, 1% | Chia OUT DAC xuống một nửa |
| R3/R8 | 1 kΩ từ OUT op-amp tới base | Tách tải base và hạn chế dòng kích |
| Q1/Q2 | onsemi 2N4401: 1=E, 2=B, 3=C | E tới sense; C tới cathode LED |
| R4/R9 | 100 Ω/100 Ω, 1%, 0,25 W; đầu dưới→GND | Đặt dòng emitter |
| J5/J6 | 1→5 V/anode; 2→collector/cathode | Không nối cathode trực tiếp GND |
| C5 | 100 nF X7R 50 V, không phân cực, 5 V–GND | Bypass gần chân 8 U1 |
| C7 | 10 µF 16 V; +→5 V, −→GND | Lọc/dự trữ nguồn đầu vào |
| C2/C4 | OUT op-amp→sense, DNP | Không lắp khi chưa đo vòng điều khiển |

Ở OUT DAC xấp xỉ 3,3 V, command xấp xỉ 1,65 V. Dòng emitter danh nghĩa
IR=16,50 mA, RED=16,50 mA; dòng LED collector thấp hơn bởi dòng base.
R4 tiêu tán khoảng 27,2 mW, R9 khoảng 27,2 mW, dưới định mức 250 mW.
Tải DAC của mỗi cầu chia khoảng 20 kΩ, tương ứng 0,165 mA full-scale.

Command 0–1,65 V nằm trong vùng common-mode LM358 dùng nguồn 5 V.
Với Vf RED=2,2 V, transistor còn khoảng 5−2,2−1,65=1,15 V VCE.
Với Vf IR=1,65 V, còn khoảng 1,70 V. Đây là tính toán DC danh nghĩa;
độ lợi transistor, offset, biên độ ra LM358 và nguồn thực ảnh hưởng dòng.
Datasheet LED trong source: YSL-R341R3D-D2 RED khuyến nghị 16–18 mA,
giới hạn DC 20 mA ở 25°C; SIR234 IR giới hạn DC 100 mA ở 25°C. Các mức
danh nghĩa đã chọn phù hợp với các linh kiện này, không tự áp dụng cho
bất kỳ LED khác. C1815 không thay trực tiếp vì thứ tự chân khác.

Không có chứng minh thực nghiệm về ổn định vòng, dòng bằng 0 tuyệt đối
hoặc overshoot. MCP4725 tải EEPROM khi bật nguồn; LED có thể sáng trước
khi phần mềm ghi 0. Mạch không có khóa tắt LED độc lập. C2/C4 để trống;
chọn bù vòng cần đo oscilloscope, không đoán giá trị tụ rồi gọi là đã ổn định.

## Kết quả kiểm tra và đưa vào sử dụng

- KiCad 10.0.6 ERC: 0 vi phạm.
- DRC: 0 vi phạm, 0 kết nối thiếu, 0 sai khác schematic/PCB.
- 244 kiểm tra độc lập về tập chân/net, giá trị linh kiện, pitch, cực tụ,
  nhãn, chiều chân transistor và hình học đạt; xem `reports/pin_contract.json`.
- 57 lỗ PTH và 4 lỗ NPTH; PCB 70×40 mm, hai lớp, FR4 1,6 mm.
- Gerber/drill, sơ đồ PDF, ảnh và ZIP được xuất từ bản v1.6.

File CAD đủ để gia công board thử. Trước khi cấp nguồn: kiểm tra chiều
module/IC, chân transistor thực mua, cực C7, pinout cáp và jumper ADDR.
Lắp thử cơ khí trên bản in 1:1 do chưa có số đo chính xác module/cáp.
Khi chạy lần đầu, kiểm tra từng địa chỉ riêng, rồi cả hai module; đặt DAC=0
trước khi tăng dần và đo điện áp trên R4/R9, dao động và quá độ. DRC sạch
không thay thế các phép đo này. Dùng bộ ZIP riêng LED driver v1.6 để in.

## Nguồn đối chiếu

- [Microchip MCP4725](https://ww1.microchip.com/downloads/aemDocuments/documents/MSLD/ProductDocuments/DataSheets/MCP4725-Data-Sheet-20002039E.pdf): VSS, A0, địa chỉ, tải DAC, I²C, EEPROM.
- [SparkFun MCP4725 breakout](https://learn.sparkfun.com/tutorials/mcp4725-digital-to-analog-converter-hookup-guide/board-overview-): GND cạnh OUT và jumper địa chỉ/pull-up; dùng làm tham chiếu loại breakout, không chứng nhận module clone.
- [TI LM358](https://www.ti.com/lit/ds/symlink/lm358.pdf): pinout, common-mode, biên độ ra, bypass.
- [onsemi 2N4401](https://www.onsemi.com/pdf/datasheet/2n4401-d.pdf): E/B/C, giới hạn linh kiện.
- [Raspberry Pi GPIO](https://www.raspberrypi.com/documentation/computers/raspberry-pi.html): GPIO2/3 có pull-up cố định.
- `docs/ds_linhkien/red_led_3.3mm_datasheet.pdf` trang 1; `IR_led_3.3mm_datasheet.pdf` trang 2–3.

Ảnh `docs/ds_linhkien/MCP4725_schematic.png` là board Adafruit khác loại;
không dùng thứ tự header trên ảnh đó thay pinout sáu chân người dùng đã xác nhận.

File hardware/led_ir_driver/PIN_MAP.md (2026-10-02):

# Tra chân PCB driver v1.9

Số chân dưới đây đọc trực tiếp từ PCB đã đi dây. Hai hình trong wiring_guide.png
đều nhìn từ mặt linh kiện; mặt đồng B.Cu được nhìn xuyên board, không lật ảnh.
Tên net giống nhau nghĩa là nối điện với nhau. Khác lớp nối qua lỗ mạ của đầu nối/socket hoặc via.
GND là vùng đồng mặt dưới, được ẩn trong hình để dễ nhìn đường tín hiệu.

Nét đứt xám nối hai pad R/C chỉ biểu diễn thân linh kiện, không phải đường đồng.

| Linh kiện | Giá trị | Chân → net |
|---|---|---|
| C2 | DNP loop comp | 1 → AMP_IR, 2 → SENSE_IR |
| C4 | DNP loop comp | 1 → AMP_RED, 2 → SENSE_RED |
| C5 | 100nF X7R 50V | 1 → 5V, 2 → GND |
| C7 | 10uF 16V | 1 → 5V, 2 → GND |
| J1 | MCP4725 IR 0x60 | 1 → DAC_IR, 2 → GND, 3 → SCL, 4 → SDA, 5 → 3V3, 6 → GND |
| J2 | PI I2C INPUT / IR OUT | 1 → DAC_IR, 2 → GND, 3 → SCL, 4 → SDA, 5 → 3V3, 6 → GND |
| J3 | MCP4725 RED 0x61 | 1 → DAC_RED, 2 → GND, 3 → SCL, 4 → SDA, 5 → 3V3, 6 → GND |
| J4 | RED DAC OUT / GND | 1 → DAC_RED, 2 → GND |
| J5 | IR LED A / K | 1 → 5V, 2 → LED_K_IR |
| J6 | RED LED A / K | 1 → 5V, 2 → LED_K_RED |
| J7 | 5V INPUT / GND | 1 → 5V, 2 → GND |
| Q1 | 2N4401 / E-B-C | 1 → SENSE_IR, 2 → BASE_IR, 3 → LED_K_IR |
| Q2 | 2N4401 / E-B-C | 1 → SENSE_RED, 2 → BASE_RED, 3 → LED_K_RED |
| R1 | 10k 1% | 1 → DAC_IR, 2 → CMD_IR |
| R2 | 10k 1% | 1 → CMD_IR, 2 → GND |
| R3 | 1k | 1 → AMP_IR, 2 → BASE_IR |
| R4 | 100R 1% 0.25W | 1 → SENSE_IR, 2 → GND |
| R6 | 10k 1% | 1 → DAC_RED, 2 → CMD_RED |
| R7 | 10k 1% | 1 → CMD_RED, 2 → GND |
| R8 | 1k | 1 → AMP_RED, 2 → BASE_RED |
| R9 | 100R 1% 0.25W | 1 → SENSE_RED, 2 → GND |
| U1 | LM358P / DIP8 socket | 1 → AMP_IR, 2 → SENSE_IR, 3 → CMD_IR, 4 → GND, 5 → CMD_RED, 6 → SENSE_RED, 7 → AMP_RED, 8 → 5V |

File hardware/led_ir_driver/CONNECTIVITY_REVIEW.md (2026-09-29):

# Rà soát kết nối — driver v1.6

Rà soát ngày 2026-09-29: xem `ELECTRICAL_AUDIT.md`. Không phát hiện nối sai
trong 17 net hiện tại; tất cả 92 đoạn đồng được giữ nguyên sau khi kiểm tra.
V1.6 sửa cách trình bày schematic và thêm nhãn cấu hình ADDR trên PCB.
Các bus chung nối bằng nhãn cùng tên; không còn đường bus xuyên thân header.

## Kết luận về đầu cáp Pi

MCP4725 (không phải MCP4275) là thiết bị I²C. Bản PCB có bốn net riêng
GND, 3V3, SCL, SDA; chỉ các chân cùng tên của hai module được nối chung.
Không có dây đồng nối bốn net này thành một. OUT IR và OUT RED tách biệt.

Thiết kế giữ đúng kiến trúc trong `docs/hardware/PPG_PROTOTYPE_SCHEMATIC.md`:
hai DAC chung bus Pi, IR 0x60, RED 0x61, cùng rail 3,3 V. Tài liệu nguồn
ghi người dùng đã đo 3,28 V; lần rà soát này không đo lại phần cứng.

| Cách đấu | Kết luận |
|---|---|
| Một bẹ I²C vào J2, hai module đã cắm | Đủ cấp nguồn và bus cho cả hai DAC |
| Hai nguồn 3,3 V độc lập, hoặc một đầu 5 V | Không phù hợp: PCB nối trực tiếp VCC, không có OR-ing/cách ly |
| Hai bộ điều khiển/bus riêng | Không thuộc cấu hình thiết kế; không nối trực tiếp như vậy |
| Nối OUT của hai module với nhau hoặc vào một ngõ ra chủ động khác | Không được; hai DAC có thể tranh chấp điện áp |

J4 hiện là header OUT_RED/GND 1×2 bước 2,54 mm trong schematic, PCB, BOM và Gerber. Việc an toàn của dây thực
vẫn phụ thuộc đúng đầu cáp, đúng chiều và đúng điện áp.

## Ánh xạ cáp bốn lõi

J2 gồm hai header đực rời: OUT/GND 1×2 bước 2,54 mm và SCL/SDA/3V3/GND 1×4 bước 2,00 mm; nối 1:1 với J1.
Dây I²C dùng nhóm **3–6**:

| Tín hiệu trên HAT/Pi | Chân trên J2 |
|---|---|
| SCL | 3 |
| SDA | 4 |
| 3,3 V | 5 |
| GND | 6 |

Chân 1 = OUT DAC, chân 2 = GND phụ. Không trượt bẹ bốn lõi lên chân 1–4.
Không suy ra thứ tự bằng màu dây; kiểm tra nhãn/tính thông mạch của cáp.
Nhóm bốn chân dùng header trần bước 2,00 mm; kiểm tra vỏ đầu cáp và thứ tự SCL/SDA/3V3/GND trước khi cắm. Không nhầm số chân J2 với số
chân vật lý trên header 40 chân của Raspberry Pi.

## Các phần đã đối chiếu

- Module: OUT/GND/SCL/SDA/VCC/GND theo ảnh; không dùng pad vuông SCL
  của module làm dấu chân 1 PCB. Điện áp 5 V của LED không tới VCC DAC.
- LM358: 1/2/3 kênh IR, 7/6/5 kênh RED, nguồn 8=5 V và 4=GND.
  Hồi tiếp âm lấy tại emitter/đầu trên điện trở sense.
- 2N4401: pad 1=E, 2=B, 3=C; không thay C1815 cùng chiều chân.
- J5/J6: anode=5 V, cathode=collector; không đưa cathode thẳng xuống GND.
- Chia áp 10k/10k: command khoảng VDAC/2. Với VDAC=3,3 V,
  dòng emitter danh nghĩa IR=16,50 mA (100 Ω), RED=16,50 mA (100 Ω).
  Dòng collector LED thấp hơn một lượng bằng dòng base.
- Tại danh nghĩa trên, điện trở sense tiêu tán khoảng 27,2/27,2 mW,
  thấp hơn công suất linh kiện 250 mW. Đây không phải chứng nhận dòng
  LED tuyệt đối: dung sai nguồn/điện trở/op-amp, Vf và headroom vẫn tác động.
- C5=100 nF gốm bypass, C7=10 µF tụ hóa lọc nguồn; C2/C4 là DNP.
  Không tự lắp giá trị tụ bù khi chưa đo vòng điều khiển.
- Hai module có điện trở pull-up; không thêm pull-up lên PCB. Kiểm tra
  mức thấp/sườn xung khi lắp cùng HAT vì các pull-up mắc song song.
- OPT101: chân 4–5 nối để dùng 1 MΩ nội, 3/8 về GND, 1 về 3,3 V,
  2/6/7 để hở. J3 xuất RED/IR, ADS1115 phải có GND chung bên ngoài.

## Đường GND

Hai chân GND của J1 và J3 (pin 2, pin 6) đều đi vào vùng đồng GND mặt dưới.
Vùng đồng này nối tới J2.2/J2.6, U1.4, R2.2, R4.2, R7.2, R9.2,
C5.2, C7.2, J4.2 và J7.2. Như vậy GND DAC, GND LM358, GND nguồn LED 5 V và
GND Pi là cùng một mốc điện áp. Dòng LED chạy về J7.2 qua vùng đồng;
không chạy qua board OPT101.

## Sửa ở v1.3

- v1.3 bỏ J4 sáu chân. v1.5 dùng lại tên J4 cho hai chân OUT_RED/GND; chỉ J2 nhận cáp Pi.
- J3 vẫn nhận 3,3 V, GND, SDA và SCL từ bus chung; J3.1 chỉ đi vào kênh Red.
- Schematic, PCB, BOM, pin map, Gerber và ảnh kiểm tra được sinh lại đồng bộ.

## Sửa đã giữ từ v1.2

- Vẽ bốn đường bus giữa hai cặp header ngay trên schematic; thêm chú thích
  dùng chung nguồn/bus và không nối chung OUT. Các nút nối có dấu chấm.
- Ghi tên từng chân bên J2, dấu ngoặc nhóm I²C 3–6, bảng chân mặt sau.
- Nhánh hồi tiếp RED đi riêng đến pad R9.1, không nhập vào đường dòng
  emitter trước pad. Nhánh C4 cũng về pad này trên lớp dưới.
- Bản đồ đồng phân biệt màu SDA/SCL và OUT IR/RED; GND pour được ẩn để
  nhìn đường tín hiệu. Đường nét đứt của linh kiện không phải dây đồng.
- Schematic OPT101 được vẽ lại thành hai mạch hoàn chỉnh có dây nguồn,
  bypass, hồi tiếp, Grove và ADS; giữ nguyên hợp đồng chân và bố trí quang.

Kiểm tra KiCad gồm ERC, DRC, kết nối chưa hoàn tất, đối chiếu schematic/PCB
và kiểm tra độc lập các tập chân/net. Chi tiết ở `reports/` của mỗi board.
Kết quả này không thay thế đo dòng, dao động, quá độ bật nguồn và thử lắp.
MCP4725 có thể nạp giá trị EEPROM khác 0 lúc khởi động; board chưa có
khóa tắt LED phần cứng. Không thể cam kết “không có sai sót” từ file CAD.

Nguồn đối chiếu:

- [Microchip MCP4725](https://ww1.microchip.com/downloads/en/DeviceDoc/MCP4725-Data-Sheet-20002039E.pdf)
- [TI LM358](https://www.ti.com/lit/ds/symlink/lm358.pdf)
- [TI OPT101](https://www.ti.com/lit/ds/symlink/opt101.pdf)
- [Seeed Grove Base Hat for Raspberry Pi](https://wiki.seeedstudio.com/Grove_Base_Hat_for_Raspberry_Pi/)

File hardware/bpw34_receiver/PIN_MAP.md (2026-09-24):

# BPW34 receiver pin map

| Reference | Pin | Net | Purpose |
|---|---:|---|---|
| D1 | 1 / K | SUM_RED | RED photodiode cathode to TIA summing node |
| D1 | 2 / A | GND_RED | RED photodiode anode |
| D2 | 1 / K | SUM_IR | IR photodiode cathode to TIA summing node |
| D2 | 2 / A | GND_IR | IR photodiode anode |
| U1/U2 | 1 | FB_RED / FB_IR | op-amp output before 100 ohm isolation resistor |
| U1/U2 | 2 | GND_RED / GND_IR | negative supply |
| U1/U2 | 3 | VREF_RED / VREF_IR | non-inverting input, approximately 0.30 V |
| U1/U2 | 4 | SUM_RED / SUM_IR | inverting input |
| U1/U2 | 5 | 3V3_RED / 3V3_IR | positive supply |
| J1 | 1,2,3,4 | OUT_RED, NC, 3V3_RED, GND_RED | Grove A2 |
| J2 | 1,2,3,4 | OUT_IR, NC, 3V3_IR, GND_IR | Grove A0 |
| J3 | 1,2,3,4 | OUT_RED, GND_RED, OUT_IR, GND_IR | ADS1115 signal/return pairs |

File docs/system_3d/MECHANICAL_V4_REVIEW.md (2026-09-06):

# Đối chiếu cơ khí v4 — 2026-09-06

Đã sửa nguồn tham số, tái sinh STL, mô hình web và ảnh. Kết quả kiểm tra hình học:
**243/243 PASS**. Dữ liệu từng phép kiểm tra: [out/fit_report.json](out/fit_report.json).

Mặt cắt và kích thước v4

## Ba vấn đề được yêu cầu

| Vấn đề | Sửa trong v4 | Kích thước kết quả |
|---|---|---|
| Tai lồi trên bốn khẩu độ | Bỏ hoàn toàn tai và phần tăng bề dày; giữ tấm phẳng chữ nhật | 62.9 × 34.9 × 1.6 mm; bịt/Ø2/Ø5/Ø16 |
| Vấu nhô dưới nắp | Bỏ hai vấu giữ board; chuyển vai giữ sang thân; khoét rãnh âm nhận khẩu độ | Rãnh rộng 2.2, sâu 1.1; ăn mép 0.8; khe trên 0.3; mái đặc 1.9 mm |
| Thiếu trục tròn đẩy carrier | Chuyển từ chi tiết chỉ hiển thị thành nguồn hình học xuất STL và xếp đủ hai bản | `12_truc_day_tron_D5x130.stl`, Ø5 × 130, vát đầu 0.4 mm |

Kiểm tra mô hình v3 tại vị trí danh nghĩa cho thấy **nắp và khẩu độ chưa có thể tích
chồng lấn**: vấu nắp nằm ở khung board phía sau (X≈135–137), còn khẩu độ ở X≈114.
Việc sửa nhằm loại bỏ tai/vấu thừa, tạo chỗ nhận tấm có khe hở rõ ràng, và giúp in/lắp.
Không suy diễn ảnh chụp thành bằng chứng đã va chạm trên CAD.

## Lỗi khác tìm được khi rà cả cụm

- Gói cũ chỉ xếp một bản mỗi mẫu, thiếu số lượng hai làn, không có trục tròn và
  khung board. V4 gồm **13 mẫu, 23 chi tiết, hai bàn in**. Tám khẩu độ là bốn cặp
  thay thế; tại mỗi thời điểm chỉ lắp hai tấm.
- Phép xoay ray D cũ chưa đưa mặt phẳng xuống mặt bàn. Nay kích thước tư thế in
  là **110 × 8 × 6.5 mm**, mặt phẳng áp bàn.
- Gối phải của ray D mở lên trên để đưa ray vào từ nóc rồi dịch trái 3 mm vào
  lỗ mù; không chỉ kiểm tra vị trí cuối mà bỏ qua đường lắp.
- Cửa dây v3 có dao cắt dừng cách mặt vách 0.5 mm. Bên +X tạo khoang kín bên
  trong nhựa. Nay bốn cửa cáp xuyên hết vách; mộng và chụp che sáng vẫn giữ.
- Lỗ giữ trục ở carrier và núm từ Ø5.1 lên Ø5.4; có vít chặn để truyền lực kéo.
  Bổ sung đúng **2 vít M3×8 ở carrier** và **2 vít M3×6 ở núm** vào danh mục.
- Nắp úp mặt ngoài phẳng xuống bàn. Khẩu độ chỉ xoay khi xuất, không còn cắt
  bớt tai bằng một hình học khác với viewer.
- Viewer và ảnh chỉ hiện một khẩu độ mỗi làn, thay vì chồng cả bốn lên nhau.
  Các đường dẫn tải STL hoạt động theo cùng cấu trúc `out/` ở local và script deploy.

## Phạm vi đo/kiểm tra

| Kiểm tra | Kết quả |
|---|---|
| Bộ STL hệ lắp ráp | 16 mẫu; watertight; mỗi mẫu một khối đặc liên thông |
| Cặp lắp của bộ đầy đủ | 339 cặp, gồm hai làn, mọi loại khẩu độ, khung, nắp, đế và hai chân màn hình |
| STL Bambu đưa về hệ lắp ráp | 241 cặp, không lấy mesh dựng mới để thay thế file xuất khi kiểm tra va chạm |
| Sai khác hình học giữa nguồn simple và STL sau xoay | Trong ngưỡng số học 0.05 mm³ của phép hiệu đối xứng |
| Trượt carrier/trục/núm | d=15..90 mm, bước 0.5 mm; 151 vị trí mỗi làn, cả full và Bambu |
| Đưa khẩu độ và khung vào thân | Quét từ trên xuống, bước 1 mm |
| Lắp ray D | Hạ ở vị trí lệch +X 3 mm, sau đó dịch trái vào lỗ mù |
| Đóng nắp khi có khẩu độ và khung | 33 vị trí, bước 0.25 mm trong 8 mm cuối |
| Lỗ/mộng/rãnh | Ray-cast điểm và boolean khối nhỏ đối chiếu độc lập |
| Hai bàn Bambu | 14 + 9 khối rời, đúng số lượng; trong bàn 256×256; mép ≥8 mm; không chồng footprint |
| Khả năng tái sinh | Cùng nguồn Python; manifest kèm SHA-256 và kích thước từng STL |

Ngưỡng giao nhau dùng để báo lỗi: **10⁻⁴ mm³**. Thể tích giao lớn nhất ở phép
kiểm tra tĩnh full khoảng 6×10⁻¹³ mm³ (sai số tính toán); ở các bước quét hành trình
và STL Bambu bằng 0 trong kết quả hiện tại.

Đã kiểm tra thêm trong Chrome headless: WebGL chạy, mỗi làn chỉ hiện một khẩu độ,
đổi khẩu độ tự ẩn tấm cũ, trục/carrier/núm đi cùng nhau ở hai đầu hành trình.
Cả 20 liên kết tải STL/manifest đều trỏ tới file có thật.

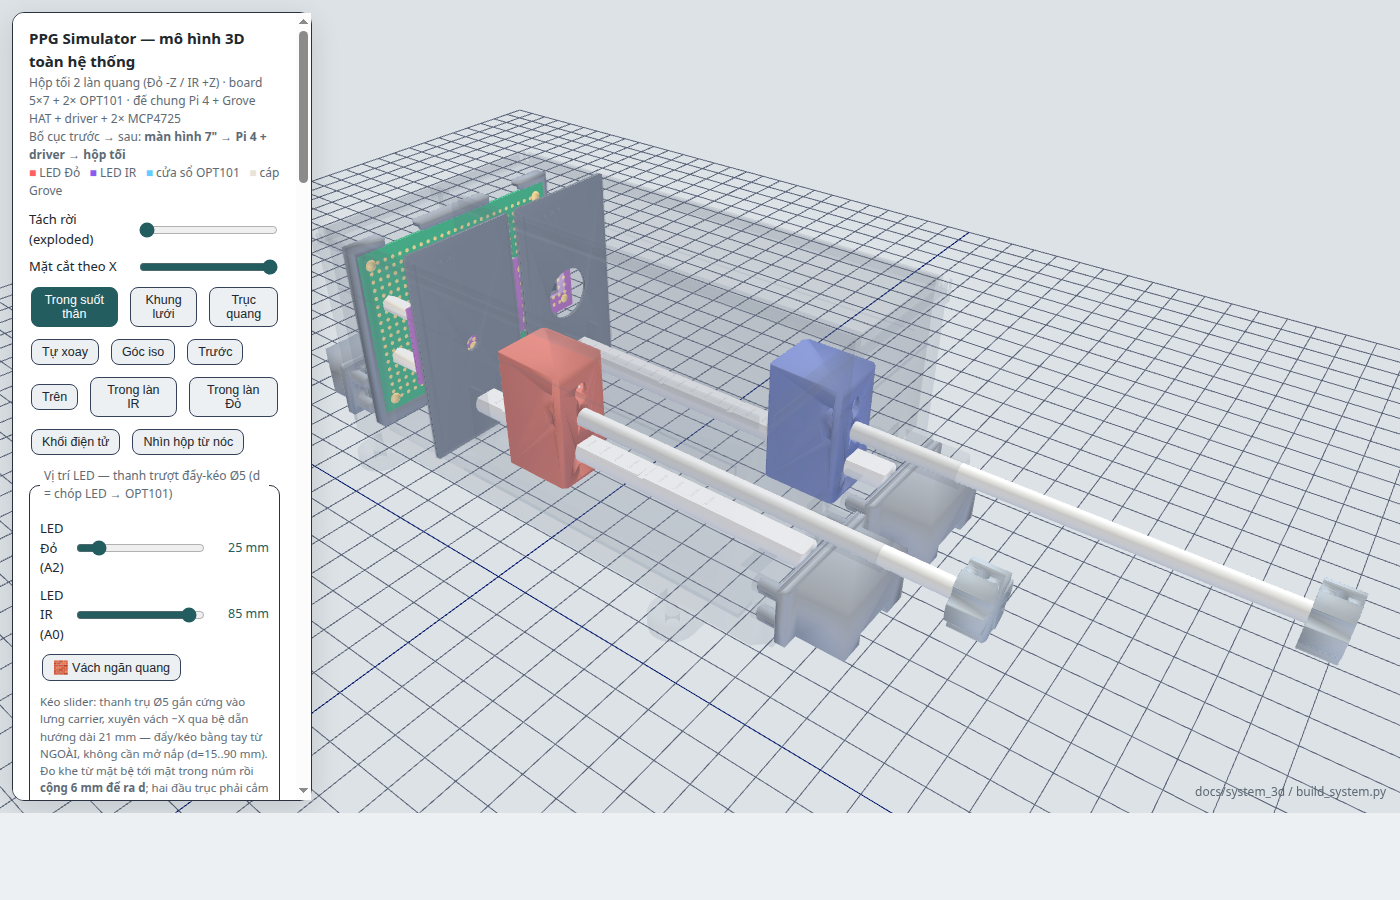
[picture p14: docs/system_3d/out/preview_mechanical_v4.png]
Mô hình v4 trong trình duyệt


## Dung sai lắp danh nghĩa

| Khớp | Khe hở hoặc độ ăn khớp (mm) |
|---|---|
| Tấm 1.6 trong rãnh thân 2.0 | 0.20 mỗi mặt |
| Tấm 1.6 trong rãnh nắp 2.2 | 0.30 mỗi mặt |
| Đỉnh tấm / đáy rãnh nắp | 0.30 |
| Tấm đi lên vào nắp | 0.80 |
| Tấm đi xuống rãnh sàn | 1.10 |
| Mép tấm / vách làn | 0.30 mỗi bên; gân chồng mép 1.30 |
| Trục Ø5 / lỗ Ø5.4 | 0.20 theo bán kính |
| Trục / carrier; trục / núm | Chiều sâu lắp 15; 6 |
| Ray D Ø8 / lỗ D carrier Ø8.5 | 0.25 theo bán kính, mặt phẳng chừa 0.25 |
| Khung board / vai trước thân | 0.30 theo X |
| Trụ chụp Ø4 / lỗ Ø4.3 | 0.15 theo bán kính |
| Gân chụp / rãnh mộng | 0.15 mỗi mặt; đáy 0.20 |

Chưa đo trên mẫu in: co ngót, nhám bề mặt, độ thẳng trục nhựa, lực đẩy/kéo,
lực giữ trụ chụp và độ rò sáng. Quét hành trình là kiểm tra mẫu rời rạc trong CAD,
không phải chứng minh liên tục hay thử nghiệm vật lý. Kích thước điện tử gắn
`[ASSUME]` vẫn phải đối chiếu linh kiện thực. Dây mềm, đầu vít mua ngoài và lớp
support/brim không nằm trong bộ khối in được dùng để kiểm tra va chạm.

Đọc [hướng dẫn in/lắp](README.md) trước khi dùng bộ mới; giữ tỷ lệ 100% để các
lỗ/trục giữ đúng đường kính. ZIP cũ `print_bambu.zip` không được ghi đè; bộ mới
có tên `print_bambu_v4.zip` để tránh nhầm hai phiên bản.

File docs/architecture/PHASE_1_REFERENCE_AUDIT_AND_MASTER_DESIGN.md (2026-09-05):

# Phase 1 — Reference Audit and Master System Design

**Project:** PPG / SpO2 Simulator on Raspberry Pi 4
**Reference device:** WhaleTeq AECG100 (PPG/SpO2 subsystem only)
**Engineering target:** ~80–90% *functional* similarity of the PPG/SpO2 subsystem — **not** the full ECG/PWTT product, and **not** clinical equivalence.
**Phase constraint:** No source code was modified in Phase 1. This document is analysis and design only.

> **Evidence discipline used throughout this report.** Every claim is tagged:
> **[VERIFIED-CODE]** = read directly from project source (file:line cited); **[VERIFIED-PDF]** = read directly from a reference PDF (page/section cited); **[VERIFIED-USER]** = user-confirmed hardware fact; **[INFERENCE]** = engineering deduction from verified facts; **[UNKNOWN]** = not determinable from currently available evidence. Where evidence is insufficient, the report states verbatim: *I am not sure based on the currently available evidence.*

---

## 1. Executive summary

The existing project is a **functional, single-channel-minded PPG/SpO2 waveform generator** that already produces dual Red/IR analog waveforms through two MCP4725 DACs and displays them in a CustomTkinter GUI. Its waveform synthesis (3-Gaussian pulse, respiration BM/AM/FM modulation, HR/PI/SpO2/RR/noise parameters) is well structured and close in spirit to the AECG100 PPG generator. **[VERIFIED-CODE]** ([models/ppg_model.py](../../models/ppg_model.py), [core/signal_engine.py](../../core/signal_engine.py), [hw/dac_manager.py](../../hw/dac_manager.py))

However, measured against the AECG100 PPG/SpO2 feature set, there are **five structural gaps** that block the 80–90% target:

1. **DAC voltage source-of-truth is wrong and duplicated.** Code hardcodes `3.3 V` full-scale in at least four places, but the **measured** full-scale is `3.2 V`. This introduces a fixed ~3% amplitude/level error on every generated AC/DC value. **[VERIFIED-CODE + VERIFIED-USER]**
2. **The SpO2 model is inverted vs. the AECG100 mental model.** The AECG100 lets the user set **AC and DC in mV per channel** and derives PI and R; the current code takes **PI as the input**, derives a single AC, and shares **one** DC baseline (`1.5 V`) across both channels. The ratio-of-ratios therefore collapses to `AC_red = R·AC_ir`, which is only valid because `DC_red == DC_ir`. **[VERIFIED-CODE]**
3. **The SpO2 calibration equation `SpO2 = A − B·R` is hardcoded** (`A=110`, `B=25`) in two places and is **not user-adjustable**. The AECG100 default is exactly `110.0 − 25.0·R` but exposes adjustable intercept/slope. **[VERIFIED-CODE + VERIFIED-PDF]**
4. **There is no receive (RX) path at all.** Two OPT101 modules exist physically (A0, A2) but there is **no acquisition code**; the only ADC code is deprecated and reads a single channel as a potentiometer. No measured-SpO2 loop exists. **[VERIFIED-CODE + VERIFIED-USER]**
5. **Configuration persistence and the reference control surface are incomplete.** `config_store` persists only 8 waveform parameters; it saves no A/B, no per-channel AC/DC(mV), no RX config. Reference features such as *AC-above/below-DC*, per-channel DC lock, and selectable single Wave-Modulation mode are absent. **[VERIFIED-CODE + VERIFIED-PDF]**

**Bottom line:** the transmit-side waveform generator is a solid ~60–70% match in *waveform behavior*, but the **SpO2 measurement architecture, calibration adjustability, RX acquisition, and voltage correctness** must be built/fixed to reach the stated engineering target. This report defines the target architecture, the exact math, the TX/RX circuit concept, the BOM, the phased plan, the files to touch (and not touch), tests, and acceptance criteria. **No clinical-grade claim is made anywhere.**

---
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

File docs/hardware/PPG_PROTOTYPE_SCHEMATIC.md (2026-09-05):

# PPG Prototype Schematic — 5 V LED Driver + Dual Optical RX

**Status: PROTOTYPE SCHEMATIC ONLY. DESIGN CALCULATED / HARDWARE NOT
VERIFIED. This is not a final PCB; no Gerbers exist or will be generated at
this stage.**

Source of every value: `docs/superpowers/ppg_design_audit/04_STAGE1_RECALCULATION_REVIEW.md`
(the Stage 1 recalculation) and the executable `led_driver` package. Evidence
labels follow `00_BASE_CONTEXT.md` §6.

## 1. Power nets

| Net | Value | Source | Allowed loads |
|---|---|---|---|
| `3V28` | 3.28 V `[VERIFIED-USER]` | Pi 3.3 V rail (measured 3.28 V) | MCP4725 ×2, OPT101 ×2, Grove Base HAT |
| `5V0` | 5.00 V `[VERIFIED-USER]` (4.75–5.25 V design window) | Pi 5 V rail | **LM358P and the two LED strings ONLY** |
| `GND` | 0 V | common ground — mandatory single reference | all |

**RULE (task-mandated): no 5 V connection to the MCP4725 modules, the OPT101s
or the Grove analog inputs — ever.** The only parts on `5V0` are the LM358P
(pin 8) and the two LED anodes.

## 2. Block overview — four separate blocks

The Red and IR paths are optically and electrically separate: two isolated
optical compartments, no shared detector, no shared optical cavity, no tissue
phantom, no WhaleTeq fixture.

```
I2C bus (Pi pins 3=SDA1, 5=SCL1, 3.3 V logic)
 ├── 0x60  MCP4725 #1 ──► IR TX driver  ──► IR LED   ─┐ optical, isolated
 ├── 0x61  MCP4725 #2 ──► Red TX driver ──► Red LED  ─┼─ compartments
 └── 0x08  Grove Base HAT ADC (MM32)                  │
        A0 ◄── OPT101 #1 (IR RX)  ◄───────────────────┘
        A2 ◄── OPT101 #2 (Red RX) ◄───────────────────┘
        A1: NEVER USED (task rule)
```
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

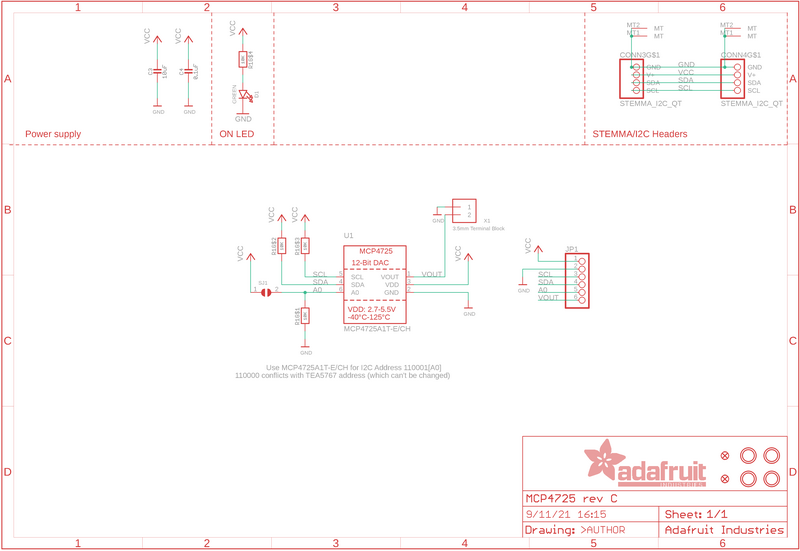
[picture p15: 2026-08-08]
docs/ds_linhkien/MCP4725_schematic.png

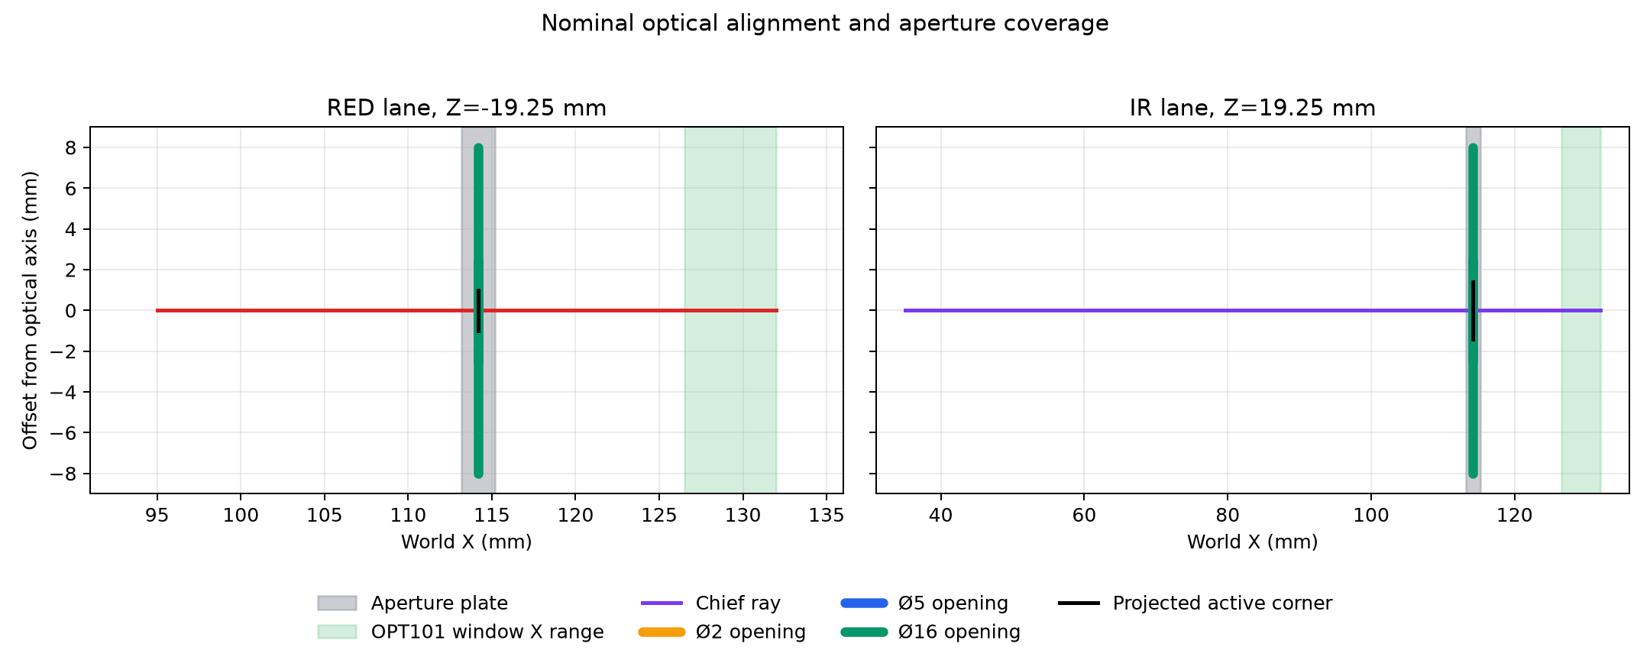
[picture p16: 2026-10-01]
hardware/opt101_receiver_kicad/opt101_receiver/mechanical/optical_alignment.png

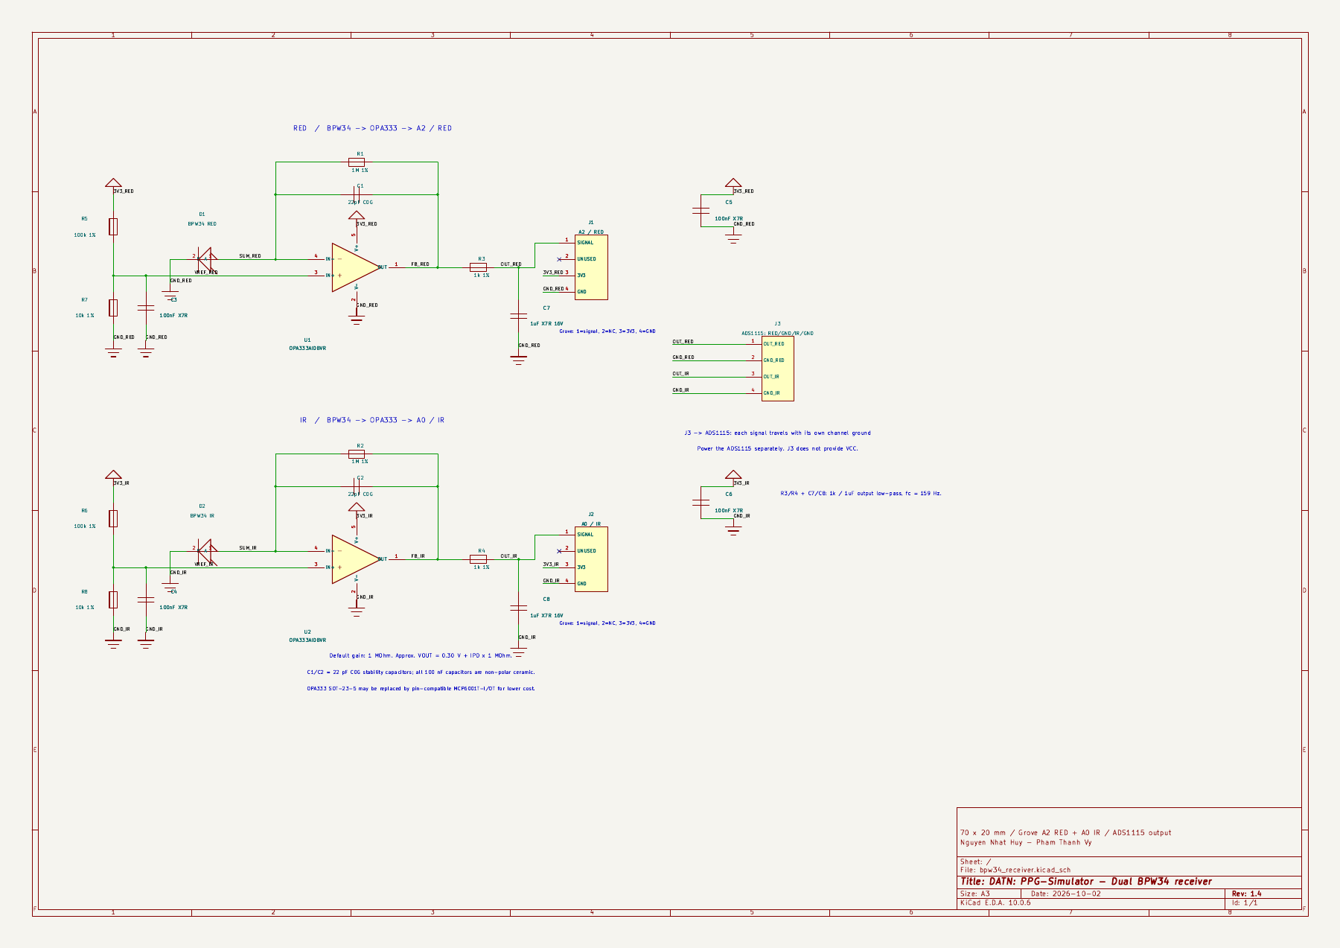
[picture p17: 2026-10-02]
hardware/bpw34_receiver/reports/schematic.png

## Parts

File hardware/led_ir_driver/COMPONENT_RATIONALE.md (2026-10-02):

# Vì sao giữ các linh kiện này? — driver v1.6

Giá trị linh kiện giữ nguyên từ v1.3; v1.6 đã đối chiếu lại nguồn, cực tụ,
chân LM358/2N4401 và hai vòng hồi tiếp. Xem `ELECTRICAL_AUDIT.md`.

## Tụ phân cực và tụ hóa có phải hai nhóm cần lắp riêng?

Không. Trong board này **C7 là một tụ hóa có phân cực**, không phải hai tụ
khác nhau. C5 là tụ gốm không phân cực. C2/C4 là vị trí tụ gốm dự phòng,
được đánh dấu DNP và không nằm trong số linh kiện cần lắp ban đầu.

| Linh kiện | Lắp ban đầu? | Vai trò và lý do chọn |
|---|---|---|
| C5, 100 nF X7R ≥25 V (BOM 50 V) | Có | Bypass nguồn LM358 tại chân 8–4, tạo đường trở kháng thấp cho nhiễu nhanh. Tụ gốm có đáp ứng cao tần tốt; đặt gần IC quan trọng hơn tăng điện dung tùy ý. |
| C7, 10 µF ≥16 V | Khuyến nghị có | Tụ dự trữ tại nguồn vào 5 V, giảm biến động do dây cấp nguồn và thay đổi tải. 10 µF là giá trị thiết kế khởi đầu, không phải giá trị tính chính xác cho mọi chiều dài dây. |
| C2/C4, chưa chọn giá trị | Không — DNP | Dự phòng bù vòng LM358–transistor nếu đo thấy rung/dao động. Không tự chọn tụ lớn vì có thể làm chậm, méo hoặc mất ổn định vòng. |

TI khuyến nghị bypass nguồn bằng tụ 0,1 µF đặt gần chân nguồn LM358.
C5 đáp ứng mục đích đó. C7 không thay thế C5; hai tụ xử lý các khoảng tần
số khác nhau. Xem [datasheet TI](https://www.ti.com/lit/ds/symlink/lm358.pdf),
mục Power Supply Recommendations và Layout.

Không bắt buộc dùng hóa học điện phân cho C7. Có thể dùng tụ gốm 10 µF
phù hợp, nhưng phải kiểm tra điện dung thực ở bias 5 V, kích thước và
footprint. Tụ hóa radial được chọn vì dễ hàn tay, dễ mua và gọn với footprint
footprint tụ hóa dán 5×5,4 mm. Cực + của C7 nối +5 V; cực − nối GND.
Nếu nguồn sát board và ổn định, có thể thử bỏ C7 sau khi đo; không khẳng định
bỏ tụ vẫn tốt khi chưa biết dây cấp nguồn/đáp ứng tải thực.

## Vì sao cần tám điện trở?

Mỗi kênh dùng bốn điện trở; hai kênh tổng cộng tám chiếc.

| Kênh IR / Red | Giá trị | Chức năng |
|---|---|---|
| R1 + R2 / R6 + R7 | Hai chiếc 10 kΩ, 1% | Chia điện áp DAC xuống một nửa: 0–3,3 V thành khoảng 0–1,65 V. |
| R3 / R8 | 1 kΩ | Giới hạn dòng nạp/base và tách ngõ ra LM358 khỏi tải điện dung của transistor. Không phải điện trở đặt dòng LED chính. |
| R4 / R9 | 100 Ω / 100 Ω, 1%, 0,25 W | Biến dòng emitter thành điện áp hồi tiếp để LM358 điều chỉnh dòng. |

**Không bỏ cầu chia rồi giữ nguyên phần còn lại.** LM358 dùng 5 V không phải
op-amp rail-to-rail. Đẩy command lên 3,3 V đòi hỏi emitter lên 3,3 V và ngõ ra
LM358 còn phải cao hơn bởi VBE và sụt áp điện trở base. Đồng thời LED đỏ cần
thêm điện áp thuận; ví dụ Vf = 2,2 V thì riêng LED + sense đã cần 5,5 V,
vượt nguồn 5 V ngay cả trước khi chừa VCE cho transistor. Chia đôi command
giữ khoảng điện áp vận hành phù hợp cho mạch hiện tại.

Hai điện trở 10 kΩ chỉ tải DAC khoảng 3,3/20.000 = 0,165 mA ở full-scale.
Tỷ số 1:1 tạo mức chia đôi; dung sai 1% giúp hạn chế sai số tỷ số, không
có nghĩa toàn mạch chính xác 1% vì còn DAC, offset LM358 và dòng base.

LM358 tăng/giảm dòng base đến khi:

```
V_sense ≈ V_command ≈ V_DAC / 2
I_emitter ≈ V_sense / R_sense
I_LED = I_collector = I_emitter − I_base
```

Ở VDAC ≈ 3,3 V:

- IR: 1,65 / 100 = 16,50 mA; công suất R4 ≈ 1,65²/100 = 0,027 W.
- Red: 1,65 / 100 = 16,50 mA; công suất R9 ≈ 0,027 W.

Chọn điện trở 0,25 W vì công suất thấp hơn đáng kể định mức, dễ mua và dễ
hàn. Đây là tính toán DC danh nghĩa; dòng collector thực thấp hơn dòng
emitter và cần hiệu chuẩn. Không thêm điện trở nối tiếp LED chỉ để đặt dòng
vì R4/R9 cùng vòng hồi tiếp đang thực hiện việc đó.

## Những gì đã bỏ khỏi bản v1.0

- **R5/R10 (DNP base–emitter):** chưa có dữ liệu yêu cầu điện trở xả bổ sung,
  nên bỏ footprint để giảm rối. Hai điện trở này vốn không được lắp.
- **C1/C3 (DNP lọc command):** chưa có yêu cầu lọc xác định; tụ có thể làm
  thay đổi dạng sóng PPG. Bỏ footprint, giữ đường DAC qua cầu chia trực tiếp.
- **C6 (100 nF ở đầu nguồn):** bỏ tụ bypass thứ hai để đơn giản hóa; giữ C5
  ngay tại IC và C7 ở đầu nguồn. Chưa có phép đo cho thấy cần thêm C6.
- Giữ nguyên tên R1–R4/R6–R9, C2/C4/C5/C7 để đối chiếu bản cũ; số thứ tự
  bị khuyết là có chủ ý, không có linh kiện còn thiếu trong BOM.

Không có kết luận thực nghiệm rằng vòng đã ổn định. C2/C4 được để trống đến
khi kiểm tra bằng oscilloscope. Việc bỏ R_BE không giải quyết và cũng không
được coi là đã giải quyết vấn đề DAC nạp EEPROM khi khởi động: LED vẫn có
thể sáng trước khi phần mềm đặt DAC về 0; board không có khóa tắt độc lập.

## Cách đọc schematic mới

- Hai socket module dùng chung bus qua nhãn SCL/SDA/3V3/GND; J2 nhận cáp Pi.
- J2.1/2 lấy OUT_IR/GND; J4.1/2 lấy OUT_RED/GND, bước chân 2,54 mm.
- OUT DAC đi bằng dây liền xuống cầu chia rồi vào chân `+` của LM358.
- Ngõ ra LM358 qua 1 kΩ đến B; C nối cathode LED; E nối đầu trên R_sense.
- Dây từ đầu trên R_sense quay về chân `−` chính là hồi tiếp âm.
- U1A (IR), U1B (Red), U1C (nguồn) là **cùng một LM358 vật lý**.
- C2/C4 có dấu gạch đỏ và dòng DNP, tách riêng khỏi mạch lắp mặc định.
- Những tên nguồn/bus giống nhau (5V, GND, SDA, SCL, 3V3) vẫn là cùng net.
  Dùng nhãn cho nguồn chung giúp tránh kéo dây dài cắt ngang toàn tờ giấy.

## Cách đọc đường PCB mới

`reports/wiring_guide.png` cho thấy hai lớp đồng, **đều từ góc nhìn mặt trên**.
Số nằm trong pad là số chân; màu thể hiện nhóm chức năng. Vùng đồng GND
được ẩn trong hình này để dễ nhìn các đường còn lại. Xem `PIN_MAP.md` để tra
chính xác chân nào chung net; bảng này được xuất từ PCB đã đi dây.

- SCL/SDA/3V3 chạy thẳng ngang ở vùng module phía trên.
- Hai OUT DAC tách nhau; không có đường đồng nối OUT IR với OUT Red.
- Tín hiệu đi dây 0,35 mm; nguồn 3,3 V 0,6 mm; nhánh 5 V và dòng LED
  0,6–0,8 mm. Tăng bề rộng giúp giảm trở kháng và dễ gia công, không phải
  vì dòng 20 mA đòi hỏi bắt buộc đường rộng 0,8 mm.
- Từ đầu trên R4/R9 có nhánh hồi tiếp riêng về ngõ đảo LM358, không lấy
  tín hiệu từ đầu cathode hoặc từ GND. Nhánh emitter mang dòng LED riêng.
- B.Cu có vùng đồng GND làm đường hồi dòng; driver nối GND về nguồn Pi/HAT
  bằng dây riêng, không chạy nối tiếp qua board thu OPT101.
- Đường khác net có thể giao nhau trên ảnh khi chúng nằm ở **hai lớp khác
  nhau**; chỉ nối qua pad xuyên lỗ. ERC/DRC kiểm tra cả hai lớp.

V1.1 đi dây bằng các tuyến tường minh trong `route_board.py`, không dùng
autorouter. Hình thức gọn và DRC sạch chưa chứng minh nhiễu, dao động hay
dòng thực; các phép đo đó vẫn cần thực hiện trên board lắp thật.

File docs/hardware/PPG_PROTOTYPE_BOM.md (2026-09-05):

# PPG Prototype BOM

**Status: PROTOTYPE BOM. DESIGN CALCULATED / HARDWARE NOT VERIFIED. No final
PCB, no Gerbers.** Reference designators match
`PPG_PROTOTYPE_SCHEMATIC.md`. Classifications come from the Stage 1 review
(`04_STAGE1_RECALCULATION_REVIEW.md` §21): FIXED = fixed by
datasheet/calculation; REC = recommended starting value; MR =
measurement-required; DNP = do not populate initially.

## 1. Active parts and modules

| Ref | Part | Package | Qty | Class | Notes |
|---|---|---|---|---|---|
| U1 | LM358P (classic, **not** LM358B/BA) | PDIP-8 | 1 | FIXED (limits) | both channels: amp A = IR, amp B = Red; classic datasheet table governs all limits |
| Q1, Q2 | 2SC1815 | TO-92 | 2 | MR (pinout, hFE bin) | datasheet order E-C-B; installed pinout DMM-confirmed before power-on |
| D1 | SIR234 IR LED, 875 nm | 3.3 mm radial | 1 | REC (operating point) | I_F abs 100 mA cont.; design full scale 20.00 mA; V_R abs max 5 V — polarity DMM-confirmed |
| D2 | YSL-R341R3D-D2 Red LED | 3.3 mm radial | 1 | REC (operating point) | I_F abs 20 mA, suggestion 16–18 mA; design full scale 16.40 mA; reverse abs max UNKNOWN — polarity DMM-confirmed |
| M1 | MCP4725 breakout (Adafruit, A1 variant) | module | 1 | — | I2C 0x60 = IR TX; VDD = 3V28 only |
| M2 | MCP4725 breakout (Adafruit, A1 variant) | module | 1 | — | I2C 0x61 = Red TX; VDD = 3V28 only |
| M3, M4 | OPT101 monolithic photodiode + TIA | DIP-8 | 2 | MR (pin 4–5 strap) | VS = 3V28 only; M3 = IR RX → A0, M4 = Red RX → A2 |
| M5 | Grove Base HAT (MM32 revision) | HAT | 1 | — | ADC 0x08, 12-bit, ref 3.28 V; A1 never used |
| — | Raspberry Pi 4, Ubuntu 24.04 | — | 1 | — | I2C SDA1/SCL1 (pins 3/5); supplies 3V28 and 5V0 |

## 2. Resistors (all fixed, 1 %, ¼ W through-hole)

| Ref | Value | Qty | Class | Role |
|---|---|---|---|---|
| R1a, R1b | 10 kΩ | 2 | ratio FIXED, value REC | IR command divider (÷2) |
| R4a, R4b | 10 kΩ | 2 | ratio FIXED, value REC | Red command divider (÷2) |
| R2 | 1 kΩ | 1 | REC | IR base series (caps shorted-R_sense drive at 2.8 mA) |
| R5 | 1 kΩ | 1 | REC | Red base series |
| R3 | 82 Ω | 1 | REC | IR R_sense → 20.00 mA full scale; 32.8 mW at FS |
| R6 | 100 Ω | 1 | REC | Red R_sense → 16.40 mA full scale; 26.9 mW at FS |
| R3be | footprint only | 1 | **MR / DNP** | IR base-emitter bleed; options DNP / 100 kΩ / 10 kΩ, chosen on the bench |
| R6be | footprint only | 1 | **MR / DNP** | Red base-emitter bleed; same options, same choice as R3be |

Divider legs for the two channels should come from the same batch (ratio
matching drives the channel gain error, Stage 1 §3).

**R_sense mounting rule (Stage 1 §16): R3 and R6 must be soldered — never
breadboard-jumpered. A shorted R_sense is the only destructive single fault
(≥ 196 mA bound).**

## 3. Capacitors

| Ref | Value | Qty | Class | Role |
|---|---|---|---|---|
| C1a, C1b | footprint + option kit: 10 nF, 100 nF, 220 nF | 2 fp + 2×3 caps | **MR / DNP** | command-node filter; both channels always fitted identically; chosen with scope on TP_CMD_* |
| C2a, C2b | footprint only | 2 | **MR / DNP** | loop compensation (op-amp out → IN−); fitted only if the bench shows instability |
| C3 | 100 nF | 1 | REC | LM358P pin 8 bypass |
| C4a | 10 µF (≥ 10 V) | 1 | REC | 5 V entry bulk |
| C4b | 100 nF | 1 | REC | 5 V entry HF |
| C5a, C5b | 100 nF | 2 | REC | one per OPT101 pin 1 (3V28) |

## 4. Test points and mechanical

| Item | Qty | Notes |
|---|---|---|
| Test-point pins/loops | 15 | TP_DAC_IR, TP_DAC_RED, TP_CMD_IR, TP_CMD_RED, TP_LM358_IR, TP_LM358_RED, TP_RSENSE_IR, TP_RSENSE_RED, TP_OPT101_IR, TP_OPT101_RED, TP_ADC_A0, TP_ADC_A2, TP_3V28, TP_5V0, TP_GND |
| Prototype board (perfboard/stripboard, soldered) | 1 | soldered construction required for the R_sense rule above; **not a PCB order — no Gerbers** |
| Opaque optical compartments | 2 | one per channel; completely isolated; no shared detector or cavity; rigid LED/OPT101 mounting with operator-adjustable, measurable spacing (Stage 6) |
| Grove analog cables | 2 | to A0 and A2 sockets; signal pin identified by continuity before use; A1 never connected |
| Hookup wire — LED-current returns vs signal returns | — | separate runs to the single ground star point (schematic §9) |

## 5. Explicitly absent from this BOM

- Any 12 V part (task: keep 5 V).
- Any part connecting 5 V to MCP4725, OPT101, or Grove analog inputs.
- A final LED-to-OPT101 spacer: the distance comes from the Stage 6
  measured sweep, never from this BOM.
- PCB fabrication items (no Gerbers at this stage).

> **Transistor identity is unconfirmed.** This document says 2SC1815 because that is the only transistor datasheet in `docs/ds_linhkien/`; the operator has stated the board carries a 2N4401. The TO-92 pinouts differ (E-C-B vs E-B-C) — verify with a DMM before soldering. See [TRANSISTOR_IDENTIFICATION.md](TRANSISTOR_IDENTIFICATION.md).

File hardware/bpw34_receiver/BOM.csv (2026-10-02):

References | Value | Package | Qty | Notes
D1,D2 | BPW34 | Vishay leaded top-view photodiode | 2 | Cathode-marked lead -> square K pad
U1,U2 | OPA333AIDBVR | SOT-23-5 | 2 | MCP6001T-I/OT is a pin-compatible low-cost alternative
R1,R2 | 1M 1% | 0805 | 2 | TIA feedback; reduce to 330k if output saturates
C1,C2 | 22pF C0G/NP0 50V | 0805 | 2 | TIA stability capacitor
R3,R4 | 1k 1% | 0805 | 2 | Output RC series resistor
R5,R6 | 100k 1% | 0805 | 2 | VREF divider top
R7,R8 | 10k 1% | 0805 | 2 | VREF divider bottom
C3,C4 | 100nF X7R 25V | 0805 | 2 | VREF filter
C7,C8 | 1uF X7R 16V | 0805 | 2 | Output RC capacitor after 1k resistor
C5,C6 | 100nF X7R 25V | 0805 | 2 | Op-amp supply bypass
J1,J2 | 1x4 male 2.00mm | THT vertical | 2 | Grove A2 RED and A0 IR
J3 | 1x4 male 2.54mm | THT vertical | 1 | OUT_RED,GND_RED,OUT_IR,GND_IR

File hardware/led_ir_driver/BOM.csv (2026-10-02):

Reference | Value | Footprint | Fit
J1 | MCP4725 IR 0x60 | TX:Socket6 | YES
J3 | MCP4725 RED 0x61 | TX:Socket6 | YES
J2 | PI I2C INPUT / IR OUT | TX:HeaderMixed | YES
J4 | RED DAC OUT / GND | TX:Header2 | YES
U1 | LM358P / DIP8 socket | TX:DIP8 | YES
Q1 | 2N4401 / E-B-C | TX:NPN | YES
R1 | 10k 1% | TX:R | YES
R2 | 10k 1% | TX:R | YES
R3 | 1k | TX:R | YES
R4 | 100R 1% 0.25W | TX:RSense | YES
C2 | DNP loop comp | TX:C | DNP
J5 | IR LED A / K | TX:Header2 | YES
Q2 | 2N4401 / E-B-C | TX:NPN | YES
R6 | 10k 1% | TX:R | YES
R7 | 10k 1% | TX:R | YES
R8 | 1k | TX:R | YES
R9 | 100R 1% 0.25W | TX:RSense | YES
C4 | DNP loop comp | TX:C | DNP
J6 | RED LED A / K | TX:Header2 | YES
J7 | 5V INPUT / GND | TX:Header2 | YES
C5 | 100nF X7R 50V | TX:C | YES
C7 | 10uF 16V | TX:CP | YES
H1 | M3 / 3.2mm | TX:Hole | YES
H2 | M3 / 3.2mm | TX:Hole | YES
H3 | M3 / 3.2mm | TX:Hole | YES
H4 | M3 / 3.2mm | TX:Hole | YES

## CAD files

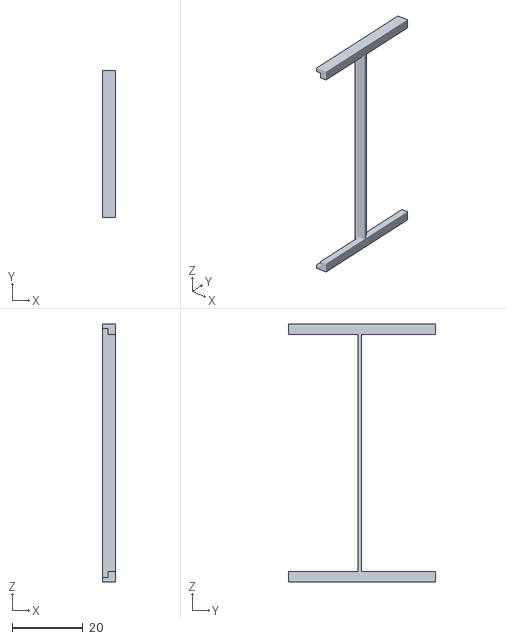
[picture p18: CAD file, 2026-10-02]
hardware/bpw34_receiver/mechanical/frame_70x20_bpw34_assembly.stl
3.80 x 41.7 x 73.0

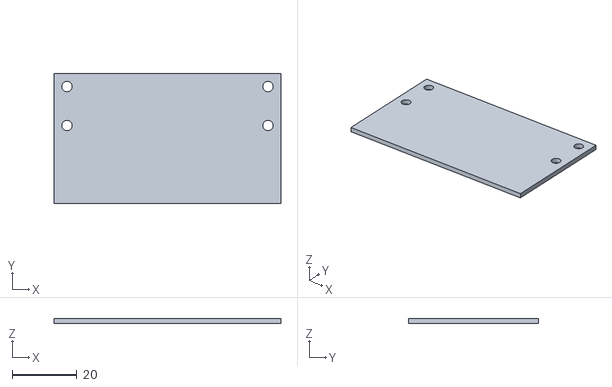
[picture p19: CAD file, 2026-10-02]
hardware/led_ir_driver/mechanical/driver_70x40_pcb_assembly.stl
70.0 x 40.0 x 1.60

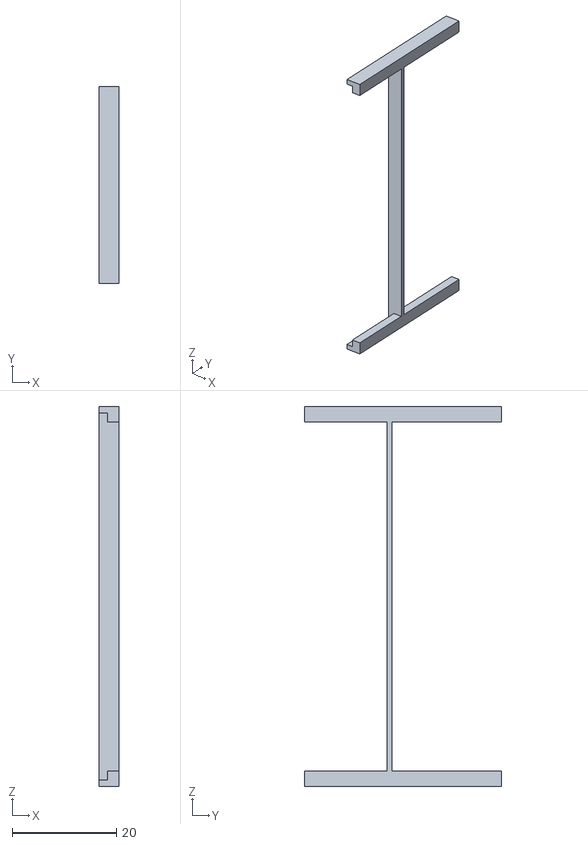
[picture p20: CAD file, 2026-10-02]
hardware/opt101_receiver_kicad/opt101_receiver/mechanical/frame_70x20_assembly.stl
3.80 x 37.8 x 73.0

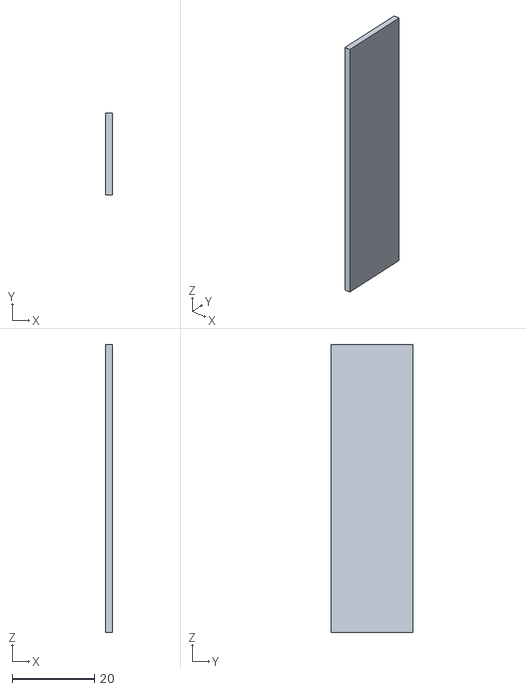
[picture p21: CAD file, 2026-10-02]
hardware/bpw34_receiver/mechanical/pcb_70x20_bpw34_assembly.stl
1.60 x 20.0 x 70.0

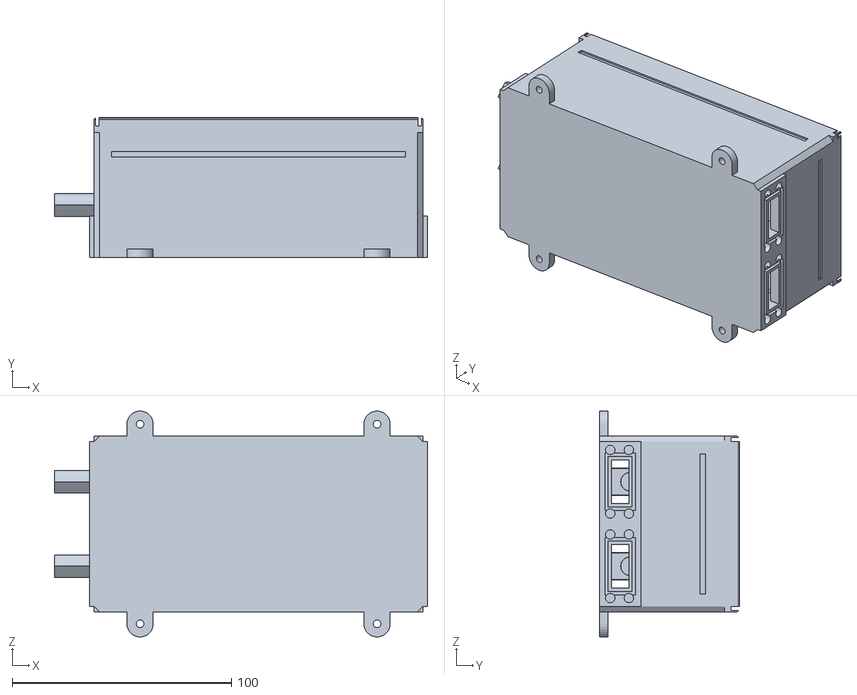
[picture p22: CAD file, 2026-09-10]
docs/system_3d/out/stl/body.stl
170.0 x 64.0 x 103.0

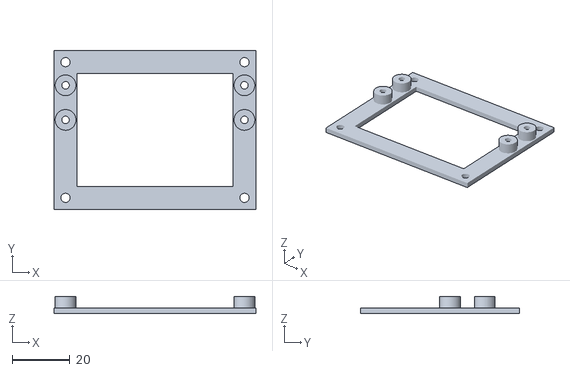
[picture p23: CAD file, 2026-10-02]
hardware/led_ir_driver/mechanical/driver_70x40_adapter_print.stl
70.0 x 55.0 x 6.00

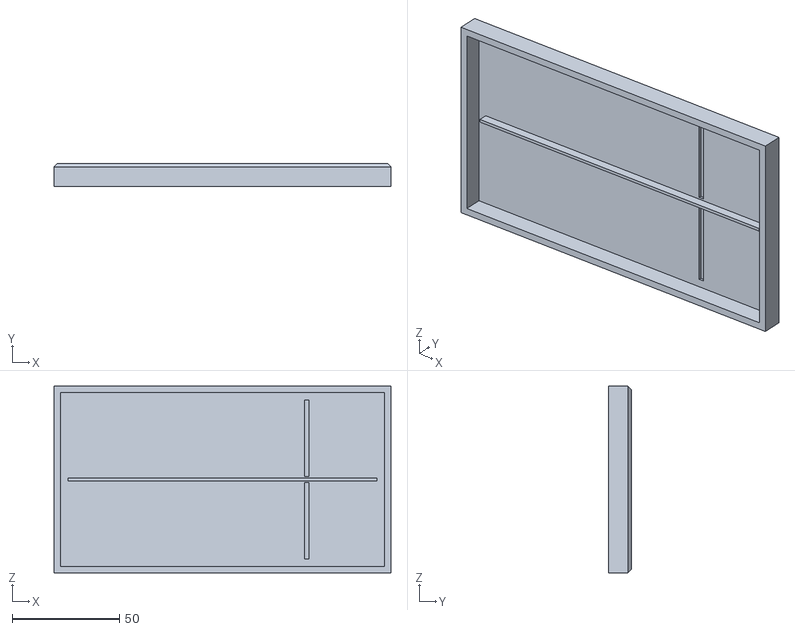
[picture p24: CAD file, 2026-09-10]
docs/system_3d/out/stl/lid.stl
157.0 x 10.5 x 87.0

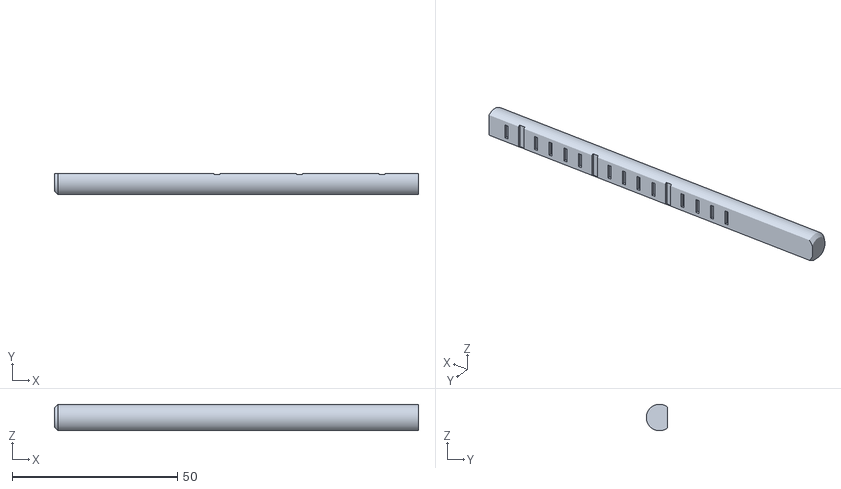
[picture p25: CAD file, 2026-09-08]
docs/system_3d/out/stl/slide_shaft_red.stl
110.2 x 6.50 x 8.00

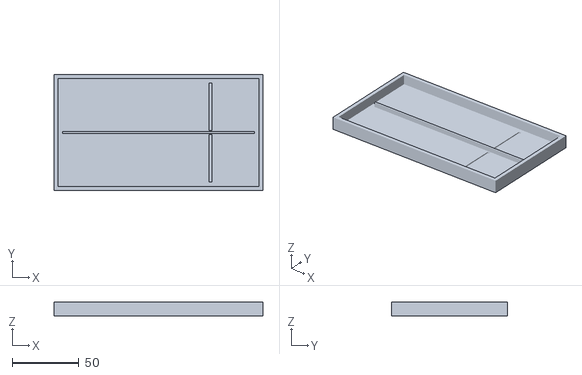
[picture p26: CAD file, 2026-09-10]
docs/system_3d/out/print_bambu_180/02_nap_labyrinth.stl
157.0 x 87.0 x 10.5

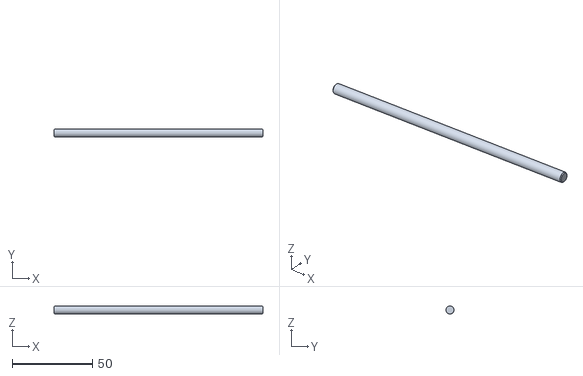
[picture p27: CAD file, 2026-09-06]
docs/system_3d/out/stl/push_rod_red.stl
130.0 x 5.00 x 5.00

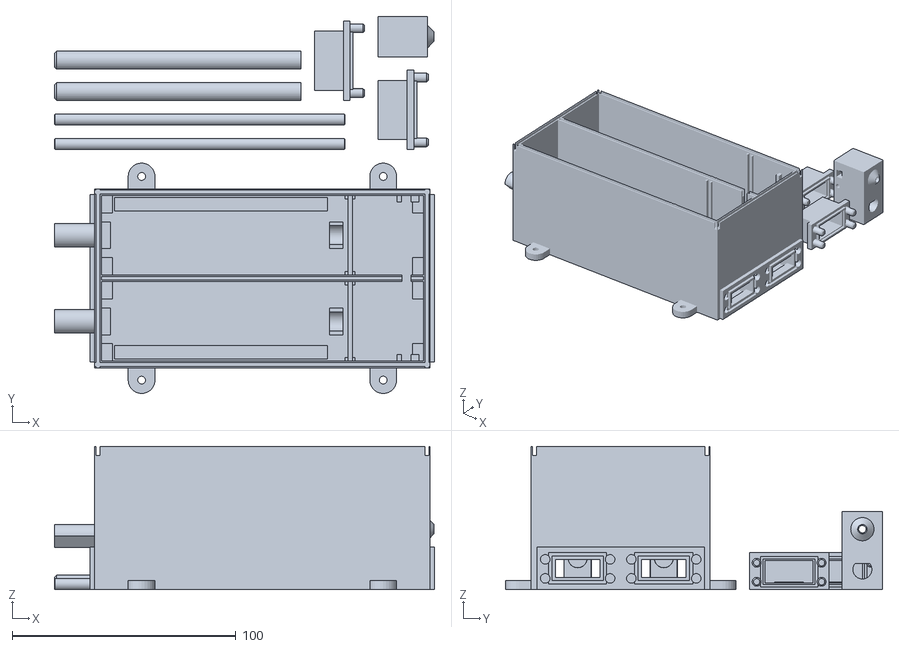
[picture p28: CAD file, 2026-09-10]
docs/system_3d/out/print_bambu_180/00_ban_1_180mm.stl
170.0 x 168.5 x 64.0

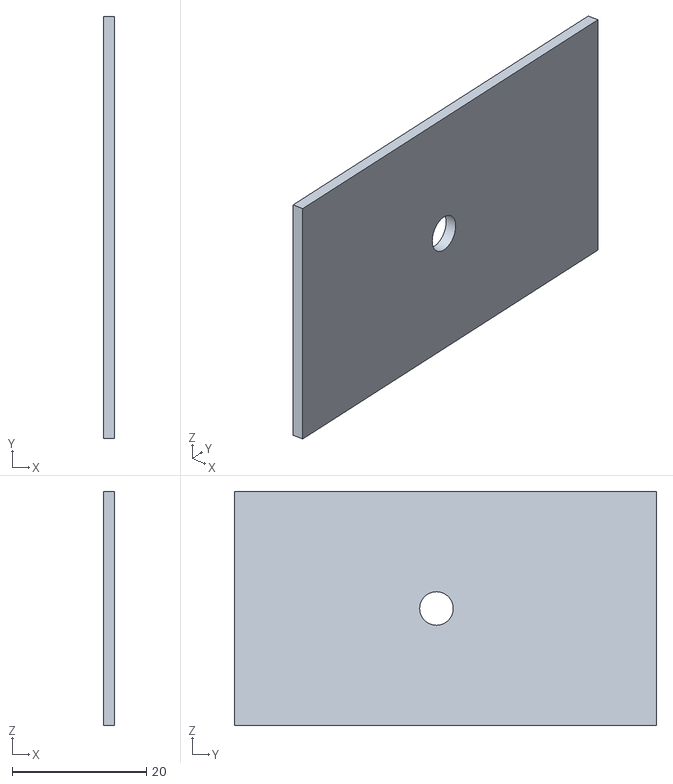
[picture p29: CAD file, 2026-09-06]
docs/system_3d/out/stl/aperture_red_d5.stl
1.60 x 62.9 x 34.9

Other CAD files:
hardware/opt101_receiver_kicad/opt101_receiver/mechanical/pcb_70x20_assembly.stl
docs/system_3d/out/print_bambu_180/15_ga_chu_U_BPW34_70x20.stl
hardware/bpw34_receiver/mechanical/frame_70x20_bpw34_print.stl
hardware/opt101_receiver_kicad/opt101_receiver/mechanical/frame_70x20_print.stl
docs/system_3d/out/print_bambu_180/14_ga_chu_U_OPT101_70x20.stl
docs/system_3d/out/print_bambu_180/00_ban_2_180mm.stl
docs/system_3d/out/print_bambu_180/00_ban_3_180mm.stl
docs/system_3d/out/print_bambu_180/01_than_hop_toi.stl
docs/system_3d/out/print_bambu_180/03_truc_truot_D.stl
docs/system_3d/out/print_bambu_180/04_carrier_led.stl
docs/system_3d/out/print_bambu_180/05_num_thanh_truot.stl
docs/system_3d/out/print_bambu_180/06_chup_luon_day_trai.stl
docs/system_3d/out/print_bambu_180/07_chup_luon_day_phai.stl
docs/system_3d/out/print_bambu_180/08_khau_do_biet.stl
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

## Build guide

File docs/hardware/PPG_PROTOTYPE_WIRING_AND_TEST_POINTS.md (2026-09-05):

# PPG Prototype Wiring, Test Points and Pre-Power Checks

**Status: DESIGN CALCULATED / HARDWARE NOT VERIFIED.** Companion to
`PPG_PROTOTYPE_SCHEMATIC.md` and `PPG_PROTOTYPE_BOM.md`. Every "expected"
value below is a calculation from the Stage 1 review
(`04_STAGE1_RECALCULATION_REVIEW.md`); none has been measured.

## 1. The 15 test points

| TP | Node | Expected @ code 0 | Expected @ 0x800 | Expected @ 4095 | Instrument |
|---|---|---|---|---|---|
| TP_DAC_IR | MCP4725 #1 VOUT (0x60) | 0.000 V | 1.640 V | 3.279 V | DMM / scope |
| TP_DAC_RED | MCP4725 #2 VOUT (0x61) | 0.000 V | 1.640 V | 3.279 V | DMM / scope |
| TP_CMD_IR | IR divider midpoint (LM358 pin 3) | 0.000 V | 0.820 V | 1.640 V | DMM / scope (C1 selection) |
| TP_CMD_RED | Red divider midpoint (LM358 pin 5) | 0.000 V | 0.820 V | 1.640 V | DMM / scope (C1 selection) |
| TP_LM358_IR | LM358 pin 1 (OUT A) | near 0 V (see note a) | ≈ 1.62–1.70 V | ≈ 2.44–2.62 V (hFE-dependent) | scope |
| TP_LM358_RED | LM358 pin 7 (OUT B) | near 0 V (note a) | ≈ 1.60–1.68 V | ≈ 2.42–2.57 V | scope |
| TP_RSENSE_IR | Q1 emitter / R3 top | 0.000 V (note a) | 0.820 V → 10.00 mA | 1.640 V → 20.00 mA | DMM (current via V/82 Ω) |
| TP_RSENSE_RED | Q2 emitter / R6 top | 0.000 V (note a) | 0.820 V → 8.20 mA | 1.640 V → 16.40 mA | DMM (current via V/100 Ω) |
| TP_OPT101_IR | OPT101 #1 pin 5 | dark baseline (MR) | rises with IR drive (MR) | < 2.13 V always (note b) | DMM / scope |
| TP_OPT101_RED | OPT101 #2 pin 5 | dark baseline (MR) | rises with Red drive (MR) | < 2.13 V always (note b) | DMM / scope |
| TP_ADC_A0 | Grove A0 signal at the socket | = TP_OPT101_IR | = TP_OPT101_IR | = TP_OPT101_IR | DMM (continuity to TP_OPT101_IR) |
| TP_ADC_A2 | Grove A2 signal at the socket | = TP_OPT101_RED | = TP_OPT101_RED | = TP_OPT101_RED | DMM |
| TP_3V28 | 3V28 rail | 3.28 V nominal — **record the actual value** (session metadata field) | ← | ← | DMM |
| TP_5V0 | 5V0 rail | 4.75–5.25 V — **record the actual value** | ← | ← | DMM |
| TP_GND | ground star point | reference | ← | ← | — |

Notes:
(a) With R_BE = DNP the residual at code 0 is MEASUREMENT-REQUIRED — the
classic LM358 table guarantees only 12 µA of sink capability near ground
(Stage 1 §14). A non-zero TP_RSENSE_* at code 0 is a finding, not a fault.
(b) `[CALCULATED]` OPT101 output ceiling ≈ VS − 1.15 V ≈ 2.13 V at 3.28 V.
Readings above ~2.1 V on TP_OPT101_*/TP_ADC_* indicate a wiring fault.
Expected RX signal values are otherwise MEASUREMENT-REQUIRED (MR) — they
depend on the LED-to-OPT101 distance, which is set in Stage 6, not here.

## 2. Wiring order (build sequence)

1. Solder the ground star point and both rails; fit C4a/C4b at the 5 V
   entry. **Do not install U1, Q1/Q2, LEDs, or connect the modules yet.**
2. Verify rails and rail isolation (§3 checks 1–3) with the DMM.
3. Solder the two dividers (R1a/R1b, R4a/R4b), C1 footprints unpopulated,
   the two R_B (R2, R5), R_sense R3/R6 (**soldered — never jumpered**,
   BOM §2 rule), and the R_BE footprints unpopulated.
4. DMM-confirm Q1/Q2 pinout and D1/D2 polarity (§4) — **before** soldering
   them in.
5. Solder Q1/Q2, D1, D2, U1 (with C3), the OPT101s (with C5a/C5b), and the
   pin 4–5 straps if absent (§4 check 3 first).
6. Wire the I2C bus (Pi pin 3 → all SDA, pin 5 → all SCL), the two Grove
   cables to A0 and A2 (signal pin identified per §3 check 5; A1 never
   connected), and the LED-current vs signal ground returns on separate
   runs (schematic §9).
7. Fit the 15 test points.
8. Run the §3 full pre-power checklist, then §5 first power-on.

## 3. Pre-power DMM checklist (all must pass before first power-on)

1. **Rails:** TP_5V0 in 4.75–5.25 V; TP_3V28 ≈ 3.28 V; record both values —
   they are required operator inputs in the capture-session metadata
   (Stage 3).
2. **Rail isolation (task rule):** with power off, resistance from `5V0` to
   every MCP4725 VDD pin, every OPT101 pin 1, and both Grove analog signal
   pins reads open. **No 5 V connection to MCP4725, OPT101 or Grove analog
   inputs.**
3. **No rail shorts:** 5V0↔GND, 3V28↔GND, 5V0↔3V28 all non-shorted.
4. **Ground continuity:** every module GND to TP_GND < 1 Ω.
5. **Grove signal-pin identification:** the Grove socket's internal pin
   order is not established by local evidence. Continuity-map the A0 and A2
   cables from the HAT socket to the wire ends before connecting the
   OPT101s; connect only the confirmed signal wire and GND; **A1 is never
   used.**
6. **Feedback wiring:** continuity LM358 pin 2 ↔ TP_RSENSE_IR and pin 6 ↔
   TP_RSENSE_RED (a broken feedback wire is the fault that can push the Red
   LED past its 20 mA abs max — Stage 1 §16).

## 4. Mandatory part-identification checks (task rule: never assume from the part name)

1. **2SC1815 pinout (Q1, Q2), before soldering.** DMM diode mode:
   - Find the base: the one pin that shows a ~0.5–0.8 V forward drop to
     **both** other pins with the red (+) lead on it (NPN).
   - Distinguish E from C: the B–E junction typically reads a few tens of
     mV **higher** than B–C. If the two readings are too close to call, use
     the DMM's hFE socket or a component tester — do not guess.
   - Record which physical lead is E/C/B and compare against the datasheet
     drawing (1=E, 2=C, 3=B). **Both transistors, individually.** A part
     that disagrees with the datasheet drawing is usable — wire it as
     measured, and record the deviation.
2. **LED polarity (D1, D2), before soldering.** DMM diode mode: exactly one
   orientation conducts. The Red LED (V_F ≈ 1.8–2.2 V) may exceed some
   DMMs' diode-test compliance voltage and read open in **both**
   directions — in that case use a 3.3 V supply through ≥ 330 Ω (≤ 10 mA)
   and observe conduction (the IR LED's emission is invisible; judge by the
   meter, not by eye). Record anode/cathode against the package. The IR
   datasheet marks pin ① = cathode; the Red datasheet has **no** polarity
   drawing — the measurement is the only evidence. A reversed IR LED would
   sit ≈ 0.2 V under its 5 V reverse abs max (Stage 1 §16) — this check is
   not optional.
3. **OPT101 pin 4 → pin 5 strap:** continuity between pins 4 and 5 on each
   assembled module. No strap = no defined transimpedance gain — do not
   power on until strapped.
4. **MCP4725 EEPROM contents (after first I2C contact, §5):** read-only
   verification of the power-up code via the DAC read command. **Never
   write EEPROM.**

## 5. First power-on procedure

1. Expectation `[CALCULATED]` Stage 1 §17: if the modules hold the factory
   EEPROM (0x800), **both LEDs turn ON at half scale at power-up** — Red
   8.2 mA, IR 10.0 mA — before any software runs. Under all ratings; not a
   fault.
2. Power on with the Pi; run `i2cdetect -y 1`: expect exactly 0x08, 0x60,
   0x61.
3. Immediately park both DACs at code 0 (the Stage 5 capture tool does this
   on start; a one-line write is acceptable during bring-up). Verify
   TP_RSENSE_IR ≈ TP_RSENSE_RED ≈ 0 V (note (a) in §1 applies).
4. Read (never write) both EEPROMs; record the power-up codes in the
   session metadata.
5. Single-channel low-code checks per the Stage 5 safety procedure: one
   channel at a time, low codes first, DMM on the channel's TP_RSENSE_*.
   The other channel stays at code 0.

## 6. Scope checks during bring-up

1. **SDA/SCL rise time:** two MCP4725 breakouts each carry their own
   pull-ups plus the HAT on one bus — verify clean edges at 100 kHz/400 kHz
   before trusting timing figures.
2. **TP_CMD_IR / TP_CMD_RED settling (C1 selection, Stage 1 §20):** with a
   1 kHz code staircase, compare DNP / 10 nF / 100 nF / 220 nF. Only 10 nF
   settles within one 1 ms update (5τ = 0.25 ms); 100/220 nF smooth across
   updates by design. Fit both channels identically.
3. **TP_LM358_* stability:** any oscillation → revisit C2 (DNP by default;
   value is bench-determined, never theoretical).
4. **TP_RSENSE_* vs TP_CMD_*:** the loop should hold them equal; a
   persistent gap beyond the Stage 1 error budget (±2 % gain, ~8 mV offset)
   is a finding.

## 7. What is deliberately not in this document

No LED-to-OPT101 distance (Stage 6 measures it; nothing is invented here),
no ADC-code-to-optical-power calibration (Stage 6), no claim that any
expected value has been observed on hardware.

> **Transistor identity is unconfirmed.** This document says 2SC1815 because that is the only transistor datasheet in `docs/ds_linhkien/`; the operator has stated the board carries a 2N4401. The TO-92 pinouts differ (E-C-B vs E-B-C) — verify with a DMM before soldering. See [TRANSISTOR_IDENTIFICATION.md](TRANSISTOR_IDENTIFICATION.md).

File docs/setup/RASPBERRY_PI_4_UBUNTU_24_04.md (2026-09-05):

# Raspberry Pi 4 — Ubuntu 24.04 LTS setup guide

Bring-up guide for the PPG simulator on a **Raspberry Pi 4** running
**Ubuntu 24.04 LTS (aarch64)**.

**Status of this document:** the software steps are testable and reproducible.
The hardware statements it points to (LED current, op-amp compliance, optical
behaviour) are **design hypotheses, not measurements** — see
[§10](#10-what-is-still-unverified).

> This guide is for **Ubuntu 24.04**. Use
> [scripts/setup_rpi_ubuntu.sh](../../scripts/setup_rpi_ubuntu.sh); legacy
> Raspberry Pi OS installers were removed because they assumed the wrong Grove
> ADC address and GPIO backend for this hardware.

---

## Hardware this guide assumes

| Item | Value |
|---|---|
| Board | 1 × Raspberry Pi 4 |
| HAT | 1 × Grove Base HAT, common ground verified |
| ADC | Grove Base HAT **MM32**, I2C **0x08**, 12-bit, Vref **3.28 V** |
| DAC — IR | MCP4725, I2C **0x60**, full scale **3.28 V** |
| DAC — Red | MCP4725, I2C **0x61**, full scale **3.28 V** |
| Op-amp | LM358P (classic PDIP), supply **5.00 V** |
| Photodiode | OPT101, supply **3.28 V** |
| RX — IR | OPT101 → ADC channel **A0** |
| RX — Red | OPT101 → ADC channel **A2** |
| A1 | unused |
| Optics | two **completely isolated** Red and IR compartments |

These match [config.py](../../config.py) exactly; step 6 re-checks that
programmatically.

---

## The one-command path

If you want the whole thing and are willing to read what it asks:

```bash
cd ~/final_project/PPG_simulator_raspi
./scripts/setup_rpi_ubuntu24.sh --enable-i2c
```

Run it **as your normal user, not with sudo.** It calls `sudo` only for `apt`
and for the two system changes it prompts about first (the boot config edit and
the `i2c` group membership). It never writes a DAC value, never toggles a GPIO,
never probes the bus and never reboots.

The rest of this document is the same work done step by step, so you can see and
check each part.

---

## 1. Confirm Ubuntu 24.04 and aarch64

```bash
cat /etc/os-release
uname -m
cat /proc/device-tree/model
```

Expected:

```
PRETTY_NAME="Ubuntu 24.04 LTS"
VERSION_ID="24.04"
aarch64
Raspberry Pi 4 Model B Rev 1.x
```

If `uname -m` reports `armv7l`, a 32-bit image was flashed. Stop here and
reflash: the aarch64 wheels in [requirements/rpi.txt](../../requirements/rpi.txt)
will not install on a 32-bit userland.

---

## 2. Enable I2C in `/boot/firmware/config.txt`

On Ubuntu for the Pi, the boot configuration lives at **`/boot/firmware/config.txt`**
(not `/boot/config.txt`, which is the older Raspberry Pi OS path). There is no
`raspi-config` on a stock Ubuntu install, so edit the file:

```bash
sudo cp -a /boot/firmware/config.txt /boot/firmware/config.txt.bak
sudo nano /boot/firmware/config.txt
```

Ensure this line is present, in the `[all]` section (or at the end of the file):

```
dtparam=i2c_arm=on
```

Optional, only if you later need a bus speed other than the 100 kHz default:

```
dtparam=i2c_arm_baudrate=100000
```

Leave the default unless you have a measured reason to change it. Faster clocks
make marginal wiring and long Grove cables fail in ways that look like software
bugs.

---

## 3. Reboot and verify `/dev/i2c-1`

The device-tree parameter is read at boot. Nothing appears until you reboot.

```bash
sudo reboot
```

After it comes back:

```bash
ls -l /dev/i2c-*
```

Expected:

```
crw-rw---- 1 root i2c 89, 1 ... /dev/i2c-1
```

`/dev/i2c-1` is the bus the Grove Base HAT sits on (GPIO2 = SDA, GPIO3 = SCL).
If it is missing, step 2 did not take effect — re-check the exact spelling of
`dtparam=i2c_arm=on` and that you edited `/boot/firmware/config.txt`.

You may also see `/dev/i2c-0` or higher-numbered buses (HDMI DDC, camera). Ignore
them; this project uses bus 1 only.

---

## 4. Configure user permissions — without `chmod 777`

Notice the mode above: `crw-rw----`, owner `root`, group `i2c`. Your user needs
to be **in that group**. That is the whole fix:

```bash
sudo usermod -aG i2c "$USER"
```

Then **log out and log back in.** Group membership is established at login;
`usermod` does not change your current session. Verify:

```bash
id -nG        # 'i2c' must appear
```

**Do not run `sudo chmod 777 /dev/i2c-1`.** It grants every process on the
system — including anything you install later — unrestricted raw access to the
bus, it does not survive a reboot (udev recreates the node), and it hides the
real problem instead of fixing it. Group membership is persistent, scoped to
your user, and is what the device node was designed for.

For the same reason, do not run the application with `sudo`. Nothing in this
project needs root.

---

## 5. Create and activate the virtual environment

Ubuntu 24.04 marks its system Python as **externally managed** (PEP 668), so
`pip install` into it is blocked — correctly. Everything goes into a project-local
venv.

```bash
cd ~/final_project/PPG_simulator_raspi

sudo apt update
sudo apt install -y python3-venv python3-dev python3-pip python3-tk \
                    build-essential git i2c-tools

python3 -m venv --system-site-packages .venv
source .venv/bin/activate

python -m pip install --upgrade pip setuptools wheel
python -m pip install -r requirements/rpi.txt

# grove.py, from the official Seeed Studio source repository:
python -m pip install --no-deps "git+https://github.com/Seeed-Studio/grove.py.git"
```

### Why each apt package

| Package | Reason |
|---|---|
| `python3-venv` | Ubuntu ships `venv` separately; without it `python3 -m venv` fails |
| `python3-dev` | headers, for any dependency lacking an aarch64 wheel |
| `python3-pip` | bootstraps pip inside the venv |
| `python3-tk` | the stdlib `tkinter`, required by `customtkinter` ([ui/ctk_app.py](../../ui/ctk_app.py)). **An OS package, not a pip package** |
| `build-essential` | C toolchain for the same source-build case |
| `git` | pip installs grove.py from a git repository |
| `i2c-tools` | provides `i2cdetect`, used in step 7 |

### Why `--system-site-packages`

It lets the venv see any vendor-supplied Python package already installed
system-wide (a distro `python3-gpiod`, a BSP module) that pip cannot reproduce on
aarch64. Project dependencies are still installed **into** the venv and shadow
anything inherited, so the dependency list stays explicit.

### Why `--no-deps` for grove.py — this one matters

grove.py's `setup.py` inspects `/proc/cpuinfo` and, when it sees a Raspberry Pi,
**appends `RPi.GPIO` and `rpi_ws281x` to `install_requires`**. Letting pip resolve
those would install the classic `RPi.GPIO` into an environment that already has
`rpi-lgpio`. Both provide the module name `RPi.GPIO`; installing both leaves which
one wins to installation order. `rpi_ws281x` is a NeoPixel driver this project
never uses. The only grove.py dependency on this project's code path is `smbus2`,
already pinned in [requirements/rpi.txt](../../requirements/rpi.txt).

### GPIO backend: `rpi-lgpio`, not `RPi.GPIO`

[hw/button_handler.py](../../hw/button_handler.py) tries `import RPi.GPIO` first
and falls back to `import lgpio`. On Ubuntu 24.04 the right way to satisfy the
first import is the **`rpi-lgpio` shim**, which presents the `RPi.GPIO` API on top
of the `lgpio` character-device backend that this kernel actually exposes. It
pulls `lgpio` as a dependency, so the fallback path works too.

**Never install both `RPi.GPIO` and `rpi-lgpio` in the same environment.**
`requirements/rpi.txt` installs only `rpi-lgpio`, and both
`scripts/setup_rpi_ubuntu24.sh` and `scripts/verify_rpi_env.py` fail loudly if
they ever find the pair.

### The MM32 at 0x08 needs no adaptation

The official `grove/adc.py` declares `def __init__(self, address = 0x04)` — the
address is a **constructor keyword**, and `0x04` is only its default.
[hw/opt101_rx.py:161](../../hw/opt101_rx.py#L161) already passes
`ADC(address=GROVE_ADC_ADDR)` with `GROVE_ADC_ADDR = 0x08`
([config.py:60](../../config.py#L60)), and `grove.i2c.Bus(bus=1)` already defaults
to `/dev/i2c-1`. **No installed file is patched, and none needs to be.** Step 6
re-checks this by introspecting the actually-installed class rather than trusting
this paragraph.

---

## 6. Run the environment verification

```bash
.venv/bin/python scripts/verify_rpi_env.py
```

It is **read-only**: it writes no DAC value, toggles no GPIO, and does not even
transact on the I2C bus. It reports `PASS` / `FAIL` / `SKIP` for:

- Linux, aarch64, Ubuntu 24.04, and the Pi model when readable
- running inside the project's own `.venv`
- `/dev/i2c-1` exists, **and your user can read/write it**
- `smbus2`, `board`, `busio`, `adafruit_mcp4725` import
- `grove.adc` imports and its `ADC` accepts an `address` argument
- `grove.i2c.Bus` defaults to bus 1
- a GPIO backend imports (`RPi.GPIO` shim and/or `lgpio`), and that
  `RPi.GPIO` + `rpi-lgpio` are **not** both installed
- `config.py` holds `0x08`, `0x60`, `0x61`, `DAC_FULLSCALE_V = 3.28`,
  `ADC_VOLTAGE_REF = 3.28`, `ADC_MAX_VALUE = 4095`, IR = A0, Red = A2
- `config.DRY_RUN` is `False` (i.e. `PPG_DRY_RUN` is not left set)

Exit status is 0 when nothing failed. `SKIP` never fails the run.

Also run the test suite on the Pi — it is hardware-independent, so it should give
the same result as on the laptop:

```bash
PPG_DRY_RUN=1 .venv/bin/python -m unittest \
    tests.test_calibration tests.test_phase3_acdc tests.test_phase4_dac \
    tests.test_phase5_rx tests.test_led_driver_dac \
    tests.test_led_driver_compliance tests.test_led_driver_power \
    tests.test_led_driver_error_budget
```

---

## 7. Scan the bus with `i2cdetect`

```bash
i2cdetect -y 1
```

No `sudo` — if you need it, step 4 is incomplete.

`i2cdetect` is not run automatically by any script here. Address scanning means
writing to every address on the bus, which can disturb a device mid-conversion;
that is a decision for you to make with the hardware in front of you, not
something a setup script should do behind your back.

---

## 8. Expected addresses

```
     0  1  2  3  4  5  6  7  8  9  a  b  c  d  e  f
00:                         08 -- -- -- -- -- -- --
...
60: 60 61 -- -- -- -- -- -- -- -- -- -- -- -- -- --
70: -- -- -- -- -- -- -- -- -- -- -- -- -- -- -- --
```

| Address | Device |
|---|---|
| `0x08` | Grove Base HAT MM32 ADC |
| `0x60` | MCP4725 — **IR** |
| `0x61` | MCP4725 — **Red** |

Reading the result:

- **A device is missing** → check the Grove cable seating, the 3.28 V supply to
  that device, and common ground. A missing DAC is usually power or wiring, not
  software.
- **Both DACs at the same address** → the A0 address pin of one MCP4725 is not
  strapped. Two devices answering one address collide and neither is usable.
- **`UU` instead of an address** → a kernel driver has claimed it. Not expected
  here.
- **Extra addresses** → other HAT peripherals. Harmless if you are not using
  them.

---

## 9. An ACK does not prove analog or optical operation

**This is the most important sentence in this guide.**

A device appearing in `i2cdetect` proves exactly one thing: a chip pulled SDA low
in response to one address byte. That is a digital handshake on two wires.

It does **not** prove any of the following:

- that the MCP4725 output pin produces the expected voltage for a given code;
- that the ÷2 attenuator ratio is what the design assumes;
- that the LM358P is inside its input common-mode range or has output headroom;
- that any current flows through either LED, or how much;
- that the sense resistors are the assumed 100 Ω / 82 Ω, or within tolerance;
- that the 2SC1815 is in its active region rather than saturated or cut off;
- that either OPT101 receives light, or produces a signal above its noise floor;
- that the Red and IR optical compartments are actually isolated from each other
  or from ambient light;
- that the AC/DC ratio, perfusion index or R value computed downstream mean
  anything physical.

Every one of those requires **physical measurement** — a multimeter for DC
operating points, an oscilloscope for waveform, timing and loop stability. Until
those measurements exist, the 5 V driver design in
[led_driver/](../../led_driver/) and
[docs/superpowers/ppg_design_audit/03_LED_DRIVER_ARCHITECTURE.md](../superpowers/ppg_design_audit/03_LED_DRIVER_ARCHITECTURE.md)
is a **calculated hypothesis**, and the 261 passing tests are evidence about
*arithmetic*, not about *hardware*.

---

## 10. What is still unverified

Completing every step above gets you a working **software** environment on the
Pi. The following remain open and must be measured on the bench:

**Electrical**
- MCP4725 output voltage vs. code, at both 0x60 and 0x61
- The divider's actual ratio and its resistors' real tolerance
- LM358P input common-mode headroom at the top of the command range
- Emitter/sense voltage and the resulting LED current at code 0 and code 4095
- Sense-resistor, transistor and LED dissipation at full scale
- Total 5 V rail current against the calculated 37.60 mA budget

**Oscilloscope**
- Loop stability and whether the `C2` compensation footprint needs a part at all
  — it is currently **DNP / MEASUREMENT-REQUIRED**
- The `R_BE` choice between 10 kΩ, 100 kΩ and DNP, including low-current
  distortion and turn-off behaviour — **not finalised, do not populate on a guess**
- Actual TX/RX sample timing, jitter and clock drift under Linux, and whether the
  1 kHz component aliases into the 0.5–4 Hz heart-rate band

**I2C**
- Bus behaviour with all three devices active at the intended sample rate
- Error, retry and timeout behaviour under load

**Optical**
- OPT101 response with the LEDs driven
- Real optical isolation between the Red and IR compartments
- Signal-to-noise ratio, saturation, and ambient-light rejection

---

## Troubleshooting

| Symptom | Cause and fix |
|---|---|
| `/dev/i2c-1` missing after reboot | `dtparam=i2c_arm=on` not in `/boot/firmware/config.txt`, or edited `/boot/config.txt` by mistake (step 2) |
| `Permission denied: /dev/i2c-1` | not in the `i2c` group, or you have not logged out and back in since `usermod` (step 4). **Do not `chmod 777`** |
| `error: externally-managed-environment` | you are pip-installing outside the venv. `source .venv/bin/activate` first (step 5) |
| `ModuleNotFoundError: No module named 'tkinter'` | `python3-tk` is an OS package: `sudo apt install python3-tk` |
| `ModuleNotFoundError: No module named 'grove'` | the `--no-deps` git install in step 5 did not run |
| `RPi.GPIO` behaving oddly | both `RPi.GPIO` and `rpi-lgpio` are installed. `pip uninstall RPi.GPIO` |
| Venv interpreter will not start | the `.venv` was copied from the x86_64 laptop. Delete it and re-run `./scripts/setup_rpi_ubuntu24.sh --recreate` |
| `i2cdetect` shows nothing | power and ground before software. Check the HAT seating and the 3.28 V rail |

---

## Related files

| File | Purpose |
|---|---|
| [scripts/setup_rpi_ubuntu24.sh](../../scripts/setup_rpi_ubuntu24.sh) | this guide, automated |
| [scripts/verify_rpi_env.py](../../scripts/verify_rpi_env.py) | read-only Pi environment check |
| [scripts/setup_laptop_venv.sh](../../scripts/setup_laptop_venv.sh) | laptop environment (no hardware) |
| [scripts/verify_laptop_env.py](../../scripts/verify_laptop_env.py) | read-only laptop check |
| [requirements/base.txt](../../requirements/base.txt) | host-portable runtime deps |
| [requirements/rpi.txt](../../requirements/rpi.txt) | Pi-only hardware deps, with reasons |
| [config.py](../../config.py) | addresses, channels, references, `DRY_RUN` |
| [docs/superpowers/ppg_design_audit/03_LED_DRIVER_ARCHITECTURE.md](../superpowers/ppg_design_audit/03_LED_DRIVER_ARCHITECTURE.md) | the 5 V driver design hypothesis |

**Never copy `.venv` between the laptop and the Pi.** The wheels are
architecture-specific and the `bin/` shebangs hardcode absolute paths. Each
machine builds its own; `.venv/` is in `.gitignore`.

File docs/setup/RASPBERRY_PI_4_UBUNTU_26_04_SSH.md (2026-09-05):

# Raspberry Pi 4 — Ubuntu 26.04 LTS over direct Ethernet and SSH

This guide connects an Ubuntu 24.04 laptop directly to a Raspberry Pi 4
running Ubuntu 26.04 LTS, copies this repository without copying x86 virtual
environments or caches, and runs software checks before hardware mode.

The examples below use the values configured on the development laptop on
2026-09-04:

| Item | Value |
|---|---|
| Laptop Ethernet interface | `enx00e04c6807fc` |
| NetworkManager profile | `rpi4-direct` |
| Laptop address | `10.42.0.1/24` |
| Stable Pi address | `10.42.0.2/24` |
| Current Pi Wi-Fi address | `192.168.16.101/24` |
| Current Pi user | `huy` |
| Working SSH alias | `ppg-rpi4` / `ppg-rpi4-wifi` |
| Reserved Ethernet alias | `ppg-rpi4-ethernet` |
| Project on Pi | `~/final_project/PPG_simulator_raspi` |

Replace `<PI_USER>` with the account created during Ubuntu's first-boot setup.
Ubuntu does not guarantee a default `pi` account.

On 2026-09-04 the verified connection is Wi-Fi at `192.168.16.101`. Both ends
of the direct Ethernet link reported `NO-CARRIER`, so the Ethernet alias below
is reserved until the cable/link LEDs are working. `ping` uses the IP address;
unlike `ssh`, it does not read aliases from `~/.ssh/config`.

Canonical lists Raspberry Pi 4B as supported by Ubuntu 26.04 LTS and publishes
the ARM64 Raspberry Pi image in its
[Raspberry Pi installation matrix](https://documentation.ubuntu.com/hardware-support/boards/how-to/ubuntu_supported/raspberry-pi/).
The EEPROM minimum and A/B boot-layout notes come from the
[Ubuntu 26.04 LTS summary](https://documentation.ubuntu.com/release-notes/26.04/summary-for-lts-users/).

## 1. One-time setup on the laptop

Find the wired interface and confirm that the cable has carrier:

```bash
ip -brief link
sudo ethtool enx00e04c6807fc | grep 'Link detected'
```

Create an isolated shared-Ethernet profile. `ipv4.method shared` gives the Pi
internet access through the laptop's Wi-Fi while keeping SSH on the cable:

```bash
nmcli connection add type ethernet \
  ifname enx00e04c6807fc \
  con-name rpi4-direct \
  ipv4.method shared \
  ipv4.addresses 10.42.0.1/24 \
  ipv6.method link-local \
  connection.autoconnect yes

nmcli connection up rpi4-direct
ip -brief address show dev enx00e04c6807fc
```

If the profile already exists, do not add it again:

```bash
nmcli connection up rpi4-direct
```

Expected laptop address: `10.42.0.1/24`.

## 2. One-time setup on the Pi console

The laptop cannot SSH until the Pi has an address and an SSH server. Attach a
keyboard/display (or serial console) to the Pi once and inspect its wired
interface name:

```bash
ip -brief link
cat /etc/os-release
uname -m
cat /proc/device-tree/model
```

Expected: Ubuntu `26.04`, `aarch64`, and `Raspberry Pi 4`. The interface is
normally `eth0`; substitute the name printed by `ip -brief link` if different.

Give the cable a stable address outside NetworkManager's shared DHCP pool:

```bash
sudo nano /etc/netplan/99-rpi4-direct.yaml
```

Enter the following, replacing `eth0` if necessary:

```yaml
network:
  version: 2
  ethernets:
    eth0:
      dhcp4: false
      addresses:
        - 10.42.0.2/24
      routes:
        - to: default
          via: 10.42.0.1
          metric: 500
      nameservers:
        addresses:
          - 10.42.0.1
      optional: false
```

Validate before applying. Do not ignore an error from `netplan generate`:

```bash
sudo chmod 600 /etc/netplan/99-rpi4-direct.yaml
sudo netplan generate
sudo netplan apply
ip -brief address
ip route
```

Install and enable SSH:

```bash
sudo apt update
sudo apt install -y openssh-server
sudo systemctl enable --now ssh
systemctl --no-pager --full status ssh
ss -ltn | grep ':22'
```

If UFW is active, allow SSH only from the direct cable:

```bash
sudo ufw status
sudo ufw allow from 10.42.0.0/24 to any port 22 proto tcp
```

Ubuntu 26.04 on Pi 4 requires boot EEPROM firmware dated 2022-11-25 or newer
for its A/B boot layout. Check it without changing it:

```bash
sudo rpi-eeprom-update
```

## 3. Commands used every time from the laptop

### Current working Wi-Fi connection

These are the short commands for this Pi as it is configured now:

```bash
ping -c 4 192.168.16.101
ssh ppg-rpi4
ssh -Y ppg-rpi4                 # open a GUI on the laptop through X11
ssh ppg-rpi4 'hostname; uptime' # run one remote command and return
```

The matching entries already written to `/home/huynn/.ssh/config` are:

```sshconfig
Host ppg-rpi4 ppg-rpi4-wifi
    HostName 192.168.16.101
    User huy
    IdentityFile /home/huynn/.ssh/id_ed25519
    IdentitiesOnly yes
    ForwardX11 yes
    ForwardX11Trusted yes
    ServerAliveInterval 30
    ServerAliveCountMax 3

Host ppg-rpi4-ethernet
    HostName 10.42.0.2
    User huy
    IdentityFile /home/huynn/.ssh/id_ed25519
    IdentitiesOnly yes
    ForwardX11 yes
    ForwardX11Trusted yes
    ServerAliveInterval 30
    ServerAliveCountMax 3
```

If DHCP later changes the Wi-Fi address, find the new address on the Pi with
`ip -brief address show wlan0` and change only the `HostName` line under the
first entry.

### Direct Ethernet after carrier is restored

Bring the cable profile up, verify reachability, then connect:

```bash
nmcli connection up rpi4-direct
ping -c 4 10.42.0.2
ssh <PI_USER>@10.42.0.2
```

The first SSH connection asks whether to trust the host key. Check the
fingerprint shown on the Pi with `ssh-keygen -lf /etc/ssh/ssh_host_ed25519_key.pub`
before answering `yes` when practical.

Create a key once so later connections do not need the account password:

```bash
ssh-keygen -t ed25519 -a 100
ssh-copy-id <PI_USER>@10.42.0.2
ssh <PI_USER>@10.42.0.2
```

The equivalent direct-cable alias in `~/.ssh/config` is:

```sshconfig
Host ppg-rpi4-ethernet
    HostName 10.42.0.2
    User huy
    IdentityFile /home/huynn/.ssh/id_ed25519
    IdentitiesOnly yes
    ForwardX11 yes
    ForwardX11Trusted yes
    ServerAliveInterval 30
    ServerAliveCountMax 3
```

After that, the short commands are:

```bash
ping -c 4 10.42.0.2
ssh ppg-rpi4-ethernet
```

If the OS image was reflashed and SSH reports a changed host key, verify the
new fingerprint on the Pi first, then remove only the old entry:

```bash
ssh-keygen -R 10.42.0.2
ssh-keygen -R 192.168.16.101
```

## 4. Copy the current source tree to the Pi

Create the destination:

```bash
ssh <PI_USER>@10.42.0.2 \
  'mkdir -p ~/final_project/PPG_simulator_raspi'
```

From the repository root on the laptop, copy source and the current
`config.json`, but never copy laptop virtual environments, Git/tool indexes,
or generated bytecode to ARM64:

```bash
cd /home/huynn/final_project/PPG_simulator_raspi

rsync -av --info=progress2 \
  --exclude='.git/' \
  --exclude='.venv/' \
  --exclude='venv/' \
  --exclude='.cad_venv/' \
  --exclude='.pio/' \
  --exclude='.pytest_cache/' \
  --exclude='.codegraph/' \
  --exclude='.codebase-memory/' \
  --exclude='__pycache__/' \
  --exclude='*.pyc' \
  ./ <PI_USER>@10.42.0.2:~/final_project/PPG_simulator_raspi/
```

This command intentionally omits `--delete`; it cannot silently remove files
that already exist on the Pi. Re-run the same command after later edits.

## 5. Build the Pi's own ARM64 environment

Run the setup in an interactive SSH terminal because `apt` and the optional
I2C changes use `sudo`:

```bash
ssh -t <PI_USER>@10.42.0.2 \
  'cd ~/final_project/PPG_simulator_raspi && ./scripts/setup_rpi_ubuntu.sh --enable-i2c'
```

Never copy `.venv` from the x86_64 laptop. The Pi must create its own ARM64
environment. If the script requests a reboot or re-login, do that before the
next checks.

Reconnect and run the read-only environment verifier:

```bash
ssh <PI_USER>@10.42.0.2 \
  'cd ~/final_project/PPG_simulator_raspi && PYTHONNOUSERSITE=1 .venv/bin/python scripts/verify_rpi_env.py'
```

Then explicitly scan the I2C bus:

```bash
ssh -t <PI_USER>@10.42.0.2 'i2cdetect -y 1'
```

Expected addresses are `0x08` (Grove MM32 ADC), `0x60` (IR MCP4725), and
`0x61` (Red MCP4725). An ACK proves bus reachability only; it does not prove
DAC voltage, LED current, OPT101 response, or optical isolation.

## 6. Run and debug over SSH

First verify the hardware-independent subset:

```bash
ssh <PI_USER>@10.42.0.2 \
  'cd ~/final_project/PPG_simulator_raspi && PYTHONNOUSERSITE=1 PPG_DRY_RUN=1 .venv/bin/python -m unittest tests.test_calibration tests.test_phase3_acdc tests.test_phase4_dac tests.test_phase5_rx tests.test_led_driver_dac tests.test_led_driver_compliance tests.test_led_driver_power tests.test_led_driver_error_budget'
```

The application is graphical. To show its window on the laptop, use X11
forwarding and keep the terminal open:

```bash
ssh -X <PI_USER>@10.42.0.2
cd ~/final_project/PPG_simulator_raspi
PYTHONNOUSERSITE=1 PYTHONUNBUFFERED=1 .venv/bin/python main.py 2>&1 | tee ~/ppg-simulator-debug.log
```

For a software-only GUI run that does not access I2C/GPIO:

```bash
PYTHONNOUSERSITE=1 PYTHONUNBUFFERED=1 .venv/bin/python main.py --dry-run
```

### Open the remote project in Antigravity IDE

The installed Antigravity IDE includes its own **Antigravity Remote - SSH**
extension. After the `ppg-rpi4` alias works in a normal terminal:

1. Press `Ctrl+Shift+P` in Antigravity IDE.
2. Run `Remote-SSH: Connect to SSH Host...`.
3. Select `ppg-rpi4` and open
   `/home/<PI_USER>/final_project/PPG_simulator_raspi`.
4. Open **Run and Debug** and select either `PPG Simulator (dry-run)` or
   `PPG Simulator (Raspberry Pi hardware)`.
5. Press `F5`.

The repository includes [`.vscode/launch.json`](../../.vscode/launch.json) and
`.vscode/settings.json`, so the remote window uses the Pi-local `.venv` and
runs `main.py` in Antigravity's integrated terminal. Add breakpoints normally.

The editor/debugger appears inside Antigravity. CustomTkinter is a native GUI,
so its application surface appears as a separate desktop window through X11,
not embedded inside an editor tab. On the Pi, install the forwarding helper if
the GUI reports that no display is available:

```bash
sudo apt install -y xauth
```

Then disconnect and reconnect the Antigravity Remote-SSH window. Verify the
remote terminal has a display before pressing `F5`:

```bash
echo "$DISPLAY"
```

It must print a value such as `localhost:10.0`. If it is empty, run the program
from a local Antigravity integrated terminal with `ssh -Y ppg-rpi4` instead;
the Tk window will still be displayed on the laptop.

Useful diagnostics from the laptop:

```bash
ssh <PI_USER>@10.42.0.2 'hostnamectl; ip -brief address; systemctl is-active ssh'
ssh <PI_USER>@10.42.0.2 'cd ~/final_project/PPG_simulator_raspi && tail -n 100 ~/ppg-simulator-debug.log'
ssh <PI_USER>@10.42.0.2 'ls -l /dev/i2c-* /dev/gpiochip*'
```

Press `Ctrl-C` in the running terminal to request a clean shutdown. The runtime
then stops acquisition and parks both DAC channels at the configured safe idle
value. A clean software shutdown still needs bench confirmation at the physical
outputs before it counts as hardware validation.

## Troubleshooting the direct cable

| Symptom | Check |
|---|---|
| Ethernet says `NO-CARRIER` | Pi power, cable seating, adapter LEDs, then `ethtool <interface>` |
| Laptop is missing `10.42.0.1` | `nmcli connection up rpi4-direct` |
| `ping 10.42.0.2` fails | Run `ip -brief address` on the Pi console; verify `eth0` and the Netplan file |
| Ping works but SSH is refused | `sudo systemctl enable --now ssh` on the Pi |
| SSH times out with UFW active | Apply the scoped UFW rule in section 2 |
| Pi cannot reach package servers | Verify laptop Wi-Fi, `ip route` on Pi, and `ping -c 2 10.42.0.1` |
| Tk reports no display | Reconnect with `ssh -X`; install `xauth` on the Pi if missing |
| `apt update` fails on `seeed.list` / `stretch` | Disable that obsolete source with `sudo mv /etc/apt/sources.list.d/seeed.list /etc/apt/sources.list.d/seeed.list.disabled`, then run `sudo apt update` again |
| Both `RPi.GPIO` and `rpi-lgpio` appear | Keep `PYTHONNOUSERSITE=1`; this hides an unrelated classic `RPi.GPIO` from `~/.local` while retaining Ubuntu's `rpi-lgpio` |
| Venv executable is wrong architecture | Remove only the Pi-side `.venv` and rerun `./scripts/setup_rpi_ubuntu.sh --recreate` |

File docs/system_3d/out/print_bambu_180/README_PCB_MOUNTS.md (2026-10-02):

# Gá PCB thu gọn dạng H

- OPT101 70×20: in `14_ga_chu_U_OPT101_70x20.stl`.
- BPW34 70×20: in `15_ga_chu_U_BPW34_70x20.stl`.
- Driver 70×40: in `16_ga_driver_70x40.stl`.

In mỗi gá cần dùng một bản; chúng chưa nằm trong các plate gốc.
Hai receiver dùng gá H không bắt vít: hai trụ cạnh và thanh ngang đỡ mép dưới PCB;
vùng dưới thanh ngang rỗng để luồn dây header ở phía trước PCB. Rãnh trong hộp
rộng 4,3 mm; gá dày 3,8 mm, hở danh nghĩa 0,5 mm theo chiều dày và 0,5 mm
mỗi bên theo chiều dài PCB. Hai biến thể có bậc đỡ khác nhau, không đổi lẫn.
In thử một đoạn gá và lắp trượt vào hộp thật trước khi in cả bộ: sai số máy in,
co vật liệu và ba via chưa thể được xác nhận bằng mô hình CAD. Không ép mạnh
nếu kẹt; mài nhẹ cạnh trụ hoặc bù kích thước theo mẫu thử. Giữ mép bằng băng
keo cách điện đục quang và bịt khe/vách chia kênh để tránh lọt sáng.
Không dùng `13_khung_board_5x7.stl` cho PCB mới. Các plate gốc thuộc mô hình gốc,
không cần in lại toàn bộ để thay gá. Hướng dẫn/giới hạn trong mechanical/README.md
của từng project; chưa thử in/lắp thực.

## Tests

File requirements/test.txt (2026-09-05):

# Full headless software suite: PPG_DRY_RUN=1 python -m pytest -q
-r base.txt
pytest>=9.0,<10
# Optional screenshot capture for scripts/smoke_ui.py (requires a display).
pillow>=12.0,<13

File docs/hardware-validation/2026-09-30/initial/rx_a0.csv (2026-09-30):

phase | monotonic_s | raw | saturated
before | 1629.847024524 | 81 | False
before | 1629.857055701 | 254 | False
before | 1629.867150004 | 71 | False
before | 1629.877139135 | 244 | False
before | 1629.887142805 | 102 | False
before | 1629.89713351 | 217 | False
before | 1629.907131124 | 74 | False
before | 1629.91713561 | 219 | False
before | 1629.927132279 | 101 | False
before | 1629.937144637 | 242 | False
before | 1629.947161681 | 77 | False
before | 1629.957174984 | 221 | False
before | 1629.967109602 | 75 | False
before | 1629.977138741 | 238 | False
before | 1629.987133614 | 101 | False
before | 1629.997138062 | 205 | False
before | 1630.007132694 | 72 | False
before | 1630.017137699 | 239 | False
before | 1630.027132645 | 73 | False
before | 1630.037137872 | 203 | False
before | 1630.047140579 | 79 | False
before | 1630.057175368 | 204 | False
before | 1630.067142957 | 65 | False
before | 1630.077158056 | 213 | False
before | 1630.087130442 | 108 | False
before | 1630.097137669 | 196 | False
before | 1630.1071313 | 104 | False
before | 1630.117131822 | 216 | False
before | 1630.127132548 | 75 | False
before | 1630.137134181 | 193 | False
before | 1630.147137982 | 76 | False
before | 1630.157136707 | 221 | False
before | 1630.167126337 | 57 | False
before | 1630.177236977 | 213 | False
before | 1630.187172558 | 102 | False
before | 1630.19720857 | 170 | False
before | 1630.207150782 | 105 | False
before | 1630.217176606 | 212 | False
before | 1630.227149622 | 70 | False
before | 1630.237155497 | 200 | False
before | 1630.247814523 | 62 | False
before | 1630.257129367 | 210 | False
before | 1630.267110774 | 96 | False
before | 1630.277152416 | 188 | False
before | 1630.287115948 | 92 | False
before | 1630.297165771 | 165 | False
before | 1630.307116532 | 72 | False
before | 1630.317142385 | 168 | False
before | 1630.32716244 | 93 | False
before | 1630.337157804 | 160 | False
before | 1630.347091524 | 93 | False
before | 1630.357146031 | 193 | False
before | 1630.367149657 | 54 | False
before | 1630.37715982 | 195 | False
before | 1630.387145293 | 88 | False
before | 1630.397136916 | 177 | False
before | 1630.407145802 | 97 | False
before | 1630.417135775 | 181 | False
before | 1630.427136122 | 65 | False
before | 1630.437139766 | 176 | False
before | 1630.447136353 | 91 | False
before | 1630.45715048 | 181 | False
before | 1630.467145048 | 64 | False
before | 1630.477134596 | 168 | False
before | 1630.487133609 | 58 | False
before | 1630.497135048 | 147 | False
before | 1630.507133246 | 90 | False
before | 1630.517136149 | 161 | False
before | 1630.527130606 | 69 | False
before | 1630.537134546 | 158 | False
before | 1630.547135467 | 61 | False
before | 1630.557161042 | 158 | False
before | 1630.567146681 | 57 | False
before | 1630.57714512 | 121 | False
before | 1630.58713176 | 87 | False
before | 1630.597135218 | 132 | False
before | 1630.60713149 | 61 | False
before | 1630.617134856 | 141 | False
before | 1630.627132925 | 63 | False
before | 1630.637132141 | 127 | False
before | 1630.647133933 | 89 | False
before | 1630.657132779 | 139 | False
before | 1630.667141054 | 84 | False
before | 1630.677142345 | 116 | False
before | 1630.687132023 | 63 | False
before | 1630.697130499 | 128 | False
before | 1630.707135309 | 61 | False
before | 1630.717132803 | 105 | False
before | 1630.72713252 | 74 | False
before | 1630.737137072 | 75 | False
before | 1630.747134418 | 54 | False
before | 1630.75713306 | 120 | False
before | 1630.767130258 | 95 | False
before | 1630.777139274 | 79 | False
before | 1630.787132582 | 57 | False
before | 1630.797144098 | 115 | False
before | 1630.8071277 | 79 | False
before | 1630.817159091 | 78 | False
before | 1630.827131783 | 76 | False
before | 1630.837137409 | 85 | False
before | 1630.847131717 | 77 | False
before | 1630.857136028 | 72 | False
before | 1630.86713317 | 50 | False
before | 1630.877134887 | 74 | False
before | 1630.887128899 | 84 | False
before | 1630.897136896 | 101 | False
before | 1630.907134223 | 54 | False
before | 1630.917139108 | 79 | False
before | 1630.927129489 | 55 | False
before | 1630.937132263 | 66 | False
before | 1630.947131535 | 84 | False
before | 1630.957131919 | 59 | False
before | 1630.967131969 | 77 | False
before | 1630.977135706 | 60 | False
before | 1630.987134515 | 56 | False
before | 1630.997134399 | 86 | False
before | 1631.007140172 | 87 | False
before | 1631.017138908 | 80 | False
before | 1631.02713479 | 86 | False
before | 1631.037138082 | 79 | False
before | 1631.047142467 | 69 | False
before | 1631.057154909 | 59 | False
before | 1631.06710956 | 87 | False
before | 1631.077216542 | 76 | False
before | 1631.087135945 | 104 | False
before | 1631.097138329 | 82 | False
before | 1631.107130822 | 55 | False
before | 1631.11713767 | 52 | False
before | 1631.127149112 | 88 | False
before | 1631.137161535 | 77 | False
before | 1631.147134543 | 120 | False
before | 1631.157136779 | 51 | False
before | 1631.167134736 | 98 | False
before | 1631.177136157 | 50 | False
before | 1631.187135874 | 119 | False
before | 1631.197139462 | 54 | False
before | 1631.207140142 | 109 | False
before | 1631.217135377 | 75 | False
before | 1631.227135853 | 113 | False
before | 1631.237129791 | 52 | False
before | 1631.247137769 | 106 | False
before | 1631.257131262 | 88 | False
before | 1631.267136351 | 131 | False
before | 1631.277130603 | 77 | False
before | 1631.287133228 | 105 | False
before | 1631.297129753 | 23 | False
before | 1631.307133907 | 121 | False
before | 1631.317133152 | 46 | False
before | 1631.327139529 | 139 | False
before | 1631.337139738 | 75 | False
before | 1631.347141836 | 124 | False
before | 1631.357130431 | 39 | False
before | 1631.367129213 | 114 | False
before | 1631.377134126 | 81 | False
before | 1631.387163916 | 154 | False
before | 1631.39714462 | 68 | False
before | 1631.407139994 | 109 | False
before | 1631.417136591 | 80 | False
before | 1631.427139133 | 127 | False
before | 1631.437134711 | 72 | False
before | 1631.447135568 | 106 | False
before | 1631.457142445 | 74 | False
before | 1631.467132781 | 127 | False
before | 1631.477143307 | 68 | False
before | 1631.487134495 | 164 | False
before | 1631.497135056 | 66 | False
before | 1631.507139191 | 141 | False
before | 1631.517136547 | 79 | False
before | 1631.527139386 | 165 | False
before | 1631.537136112 | 66 | False
before | 1631.547144434 | 210 | False
before | 1631.557138734 | 52 | False
before | 1631.567133886 | 158 | False
before | 1631.577131483 | 100 | False
before | 1631.587137322 | 201 | False
before | 1631.597131585 | 41 | False
before | 1631.60713635 | 219 | False
before | 1631.617131095 | 97 | False
before | 1631.627134804 | 178 | False
before | 1631.637135828 | 101 | False
before | 1631.647139945 | 201 | False
before | 1631.657135504 | 93 | False
before | 1631.667135806 | 159 | False
before | 1631.677141275 | 101 | False
before | 1631.687141891 | 235 | False
before | 1631.697130893 | 87 | False
before | 1631.707135084 | 213 | False
before | 1631.717131922 | 104 | False
before | 1631.727132927 | 197 | False
before | 1631.73713145 | 111 | False
before | 1631.747131899 | 225 | False
before | 1631.757136257 | 120 | False
before | 1631.767143245 | 223 | False
before | 1631.777142157 | 97 | False
before | 1631.7871309 | 192 | False
before | 1631.797133443 | 112 | False
before | 1631.807132429 | 245 | False
before | 1631.817135194 | 115 | False
before | 1631.827136717 | 259 | False
before | 1631.837132814 | 88 | False
output | 1631.847131596 | 205 | False
output | 1631.857134324 | 99 | False
output | 1631.873516668 | 237 | False
output | 1631.878066067 | 130 | False
output | 1631.886988231 | 244 | False
output | 1631.897775158 | 129 | False
output | 1631.90742649 | 258 | False
output | 1631.91770128 | 131 | False
output | 1631.927613061 | 295 | False
output | 1631.937395257 | 135 | False
output | 1631.948042596 | 309 | False
output | 1631.957773687 | 134 | False
output | 1631.967066548 | 236 | False
output | 1631.977451845 | 138 | False
output | 1631.987025344 | 241 | False
output | 1631.997327178 | 102 | False
output | 1632.007411721 | 262 | False
output | 1632.017655504 | 107 | False
output | 1632.02740597 | 265 | False
output | 1632.037682057 | 92 | False
output | 1632.047397848 | 262 | False
output | 1632.057557279 | 106 | False
output | 1632.067071727 | 249 | False
output | 1632.077595575 | 125 | False
output | 1632.087430709 | 287 | False
output | 1632.097497358 | 102 | False
output | 1632.107403768 | 275 | False
output | 1632.117461879 | 98 | False
output | 1632.12739998 | 292 | False
output | 1632.13760431 | 100 | False
output | 1632.147636044 | 321 | False
output | 1632.157437652 | 118 | False
output | 1632.167661282 | 243 | False
output | 1632.177134129 | 95 | False
output | 1632.187735809 | 281 | False
output | 1632.197367692 | 100 | False
output | 1632.207603455 | 265 | False
output | 1632.21771456 | 113 | False
output | 1632.227509073 | 311 | False
output | 1632.237273042 | 122 | False
output | 1632.247421266 | 303 | False
output | 1632.25708047 | 119 | False
output | 1632.267818126 | 304 | False
output | 1632.277085926 | 99 | False
output | 1632.287683402 | 322 | False
output | 1632.297568817 | 101 | False
output | 1632.307421002 | 285 | False
output | 1632.317636659 | 105 | False
output | 1632.327679425 | 308 | False
output | 1632.337031792 | 99 | False
output | 1632.347409023 | 305 | False
output | 1632.357662318 | 137 | False
output | 1632.367447673 | 318 | False
output | 1632.377295949 | 134 | False
output | 1632.387405804 | 292 | False
output | 1632.397085598 | 146 | False
output | 1632.407502468 | 295 | False
output | 1632.417396792 | 101 | False
output | 1632.427468342 | 328 | False
output | 1632.437310988 | 140 | False
output | 1632.447621981 | 343 | False
output | 1632.457056478 | 122 | False
output | 1632.467517136 | 330 | False
output | 1632.477317661 | 141 | False
output | 1632.48740314 | 320 | False
output | 1632.497412768 | 130 | False
output | 1632.507399354 | 310 | False
output | 1632.517679637 | 132 | False
output | 1632.527462084 | 338 | False
output | 1632.537672129 | 122 | False
output | 1632.547104384 | 283 | False
output | 1632.557695016 | 132 | False
output | 1632.567051865 | 242 | False
output | 1632.577477941 | 121 | False
output | 1632.58741446 | 346 | False
output | 1632.597473618 | 148 | False
output | 1632.607393781 | 315 | False
output | 1632.617584562 | 123 | False
output | 1632.627365564 | 334 | False
output | 1632.637437762 | 134 | False
output | 1632.647228952 | 315 | False
output | 1632.657465484 | 148 | False
output | 1632.667099601 | 303 | False
output | 1632.67762042 | 145 | False
output | 1632.687377324 | 336 | False
output | 1632.697423053 | 114 | False
output | 1632.707419438 | 344 | False
output | 1632.71748369 | 116 | False
output | 1632.727402464 | 359 | False
output | 1632.737558793 | 145 | False
output | 1632.74750963 | 327 | False
output | 1632.757385172 | 146 | False
output | 1632.767113273 | 320 | False
output | 1632.777466684 | 111 | False
output | 1632.78745916 | 327 | False
output | 1632.79776945 | 102 | False
output | 1632.807895531 | 355 | False
output | 1632.817639895 | 120 | False
output | 1632.827543295 | 328 | False
output | 1632.837500523 | 104 | False
output | 1632.847765432 | 379 | False
output | 1632.857398418 | 123 | False
output | 1632.86769289 | 362 | False
output | 1632.877735192 | 105 | False
output | 1632.887410188 | 344 | False
output | 1632.89740222 | 113 | False
output | 1632.907475733 | 325 | False
output | 1632.917084844 | 156 | False
output | 1632.927605386 | 349 | False
output | 1632.937416895 | 98 | False
output | 1632.947691547 | 347 | False
output | 1632.957625195 | 137 | False
output | 1632.967399214 | 327 | False
output | 1632.977093233 | 107 | False
output | 1632.98759377 | 336 | False
output | 1632.997389831 | 129 | False
output | 1633.007410351 | 353 | False
output | 1633.017088477 | 145 | False
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

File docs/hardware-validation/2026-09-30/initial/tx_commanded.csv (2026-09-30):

time_s | ir_v | red_v
0.0 | 1.516985492259264 | 1.5081530362844466
0.01 | 1.515734328120947 | 1.5075524774980544
0.02 | 1.5144831639826297 | 1.5069519187116622
0.03 | 1.5133409814834595 | 1.5064036711120605
0.04 | 1.512307780623436 | 1.505907734699249
0.05 | 1.5112745797634124 | 1.505411798286438
0.06 | 1.5106838580965996 | 1.5051282518863678
0.07 | 1.5100931364297867 | 1.5048447054862977
0.08 | 1.5097001516371966 | 1.5046560727858544
0.09 | 1.509504903718829 | 1.5045623537850379
0.1 | 1.5093096558004617 | 1.5044686347842215
0.11 | 1.5094883746057748 | 1.5045544198107719
0.12 | 1.509667093411088 | 1.5046402048373222
0.13 | 1.5096888771057129 | 1.5046506610107422
0.14 | 1.5095537256896496 | 1.5045857883310318
0.15 | 1.5094185742735862 | 1.5045209156513215
0.16 | 1.5091506044268608 | 1.5043922901248932
0.17 | 1.5088826345801354 | 1.5042636645984648
0.18 | 1.5083139727413655 | 1.5039907069158553
0.19 | 1.507444618910551 | 1.5035734170770645
0.2 | 1.5065752650797366 | 1.5031561272382736
0.21 | 1.5057185390889645 | 1.502744898762703
0.22 | 1.5048618130981921 | 1.5023336702871322
0.23 | 1.5040234296955168 | 1.501931246253848
0.24 | 1.5032033888809382 | 1.5015376266628504
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

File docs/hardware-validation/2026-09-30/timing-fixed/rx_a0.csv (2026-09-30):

phase | monotonic_s | raw | saturated
before | 1751.256328722 | 84 | False
before | 1751.266303723 | 102 | False
before | 1751.276481035 | 105 | False
before | 1751.286431957 | 104 | False
before | 1751.296419494 | 110 | False
before | 1751.306418625 | 117 | False
before | 1751.316437741 | 90 | False
before | 1751.326422314 | 121 | False
before | 1751.336454414 | 90 | False
before | 1751.346420984 | 134 | False
before | 1751.356425153 | 81 | False
before | 1751.366418357 | 150 | False
before | 1751.376419488 | 137 | False
before | 1751.386417471 | 148 | False
before | 1751.396419899 | 105 | False
before | 1751.406421716 | 94 | False
before | 1751.41642457 | 117 | False
before | 1751.42643724 | 109 | False
before | 1751.436441594 | 145 | False
before | 1751.44641524 | 148 | False
before | 1751.456412611 | 124 | False
before | 1751.466415521 | 118 | False
before | 1751.476415985 | 113 | False
before | 1751.486413764 | 136 | False
before | 1751.496415562 | 92 | False
before | 1751.506421194 | 118 | False
before | 1751.516416417 | 96 | False
before | 1751.526417956 | 114 | False
before | 1751.536428534 | 126 | False
before | 1751.546412755 | 140 | False
before | 1751.556412219 | 137 | False
before | 1751.566417111 | 121 | False
before | 1751.576411834 | 86 | False
before | 1751.586414021 | 152 | False
before | 1751.596413596 | 119 | False
before | 1751.606418228 | 130 | False
before | 1751.616414525 | 103 | False
before | 1751.626424473 | 120 | False
before | 1751.636424141 | 109 | False
before | 1751.646424717 | 131 | False
before | 1751.657180584 | 155 | False
before | 1751.66639416 | 116 | False
before | 1751.676416091 | 110 | False
before | 1751.686415833 | 97 | False
before | 1751.696415464 | 154 | False
before | 1751.706416484 | 121 | False
before | 1751.716421468 | 151 | False
before | 1751.726415562 | 106 | False
before | 1751.73642136 | 115 | False
before | 1751.746426511 | 104 | False
before | 1751.756422086 | 130 | False
before | 1751.766414808 | 105 | False
before | 1751.776411884 | 128 | False
before | 1751.786414349 | 102 | False
before | 1751.796415369 | 143 | False
before | 1751.806411888 | 139 | False
before | 1751.816423521 | 152 | False
before | 1751.826415466 | 139 | False
before | 1751.836412152 | 114 | False
before | 1751.846415766 | 149 | False
before | 1751.856414304 | 149 | False
before | 1751.866423881 | 106 | False
before | 1751.876421568 | 97 | False
before | 1751.886421106 | 142 | False
before | 1751.896413255 | 158 | False
before | 1751.906414719 | 105 | False
before | 1751.916413406 | 112 | False
before | 1751.926414482 | 120 | False
before | 1751.936412372 | 143 | False
before | 1751.946479403 | 159 | False
before | 1751.956473422 | 128 | False
before | 1751.966415322 | 141 | False
before | 1751.976402006 | 133 | False
before | 1751.986335941 | 85 | False
before | 1751.996300437 | 124 | False
before | 1752.00654872 | 133 | False
before | 1752.016455558 | 117 | False
before | 1752.026425314 | 125 | False
before | 1752.03642389 | 106 | False
before | 1752.046424576 | 107 | False
before | 1752.056419503 | 122 | False
before | 1752.066422894 | 125 | False
before | 1752.076420766 | 121 | False
before | 1752.086424972 | 113 | False
before | 1752.096427455 | 103 | False
before | 1752.106425901 | 110 | False
before | 1752.116428736 | 137 | False
before | 1752.126447222 | 137 | False
before | 1752.136416441 | 124 | False
before | 1752.146423685 | 94 | False
before | 1752.1564185 | 150 | False
before | 1752.166456156 | 117 | False
before | 1752.176433895 | 155 | False
before | 1752.18642834 | 84 | False
before | 1752.196426156 | 128 | False
before | 1752.206449809 | 117 | False
before | 1752.216418954 | 108 | False
before | 1752.226434421 | 140 | False
before | 1752.236422143 | 57 | False
before | 1752.246422904 | 76 | False
before | 1752.256428369 | 124 | False
before | 1752.266419703 | 118 | False
before | 1752.276421316 | 109 | False
before | 1752.286420206 | 143 | False
before | 1752.296422928 | 110 | False
before | 1752.306445467 | 102 | False
before | 1752.316392549 | 128 | False
before | 1752.326429776 | 122 | False
before | 1752.336429644 | 145 | False
before | 1752.346419604 | 116 | False
before | 1752.356423992 | 114 | False
before | 1752.366422471 | 99 | False
before | 1752.376420155 | 144 | False
before | 1752.386421338 | 119 | False
before | 1752.396425337 | 119 | False
before | 1752.406419038 | 140 | False
before | 1752.416421593 | 95 | False
before | 1752.426421054 | 93 | False
before | 1752.436443482 | 108 | False
before | 1752.44643809 | 133 | False
before | 1752.456418233 | 99 | False
before | 1752.466418898 | 112 | False
before | 1752.476421119 | 155 | False
before | 1752.48650878 | 137 | False
before | 1752.496418486 | 148 | False
before | 1752.506422355 | 98 | False
before | 1752.516422187 | 125 | False
before | 1752.526525665 | 147 | False
before | 1752.536480712 | 97 | False
before | 1752.546429868 | 105 | False
before | 1752.556426144 | 121 | False
before | 1752.566418678 | 148 | False
before | 1752.576418621 | 126 | False
before | 1752.586420656 | 102 | False
before | 1752.596418006 | 121 | False
before | 1752.606419727 | 123 | False
before | 1752.616421503 | 129 | False
before | 1752.626420261 | 98 | False
before | 1752.636424241 | 129 | False
before | 1752.646422387 | 135 | False
before | 1752.656428831 | 136 | False
before | 1752.666428718 | 114 | False
before | 1752.676426568 | 144 | False
before | 1752.686427919 | 103 | False
before | 1752.696418601 | 106 | False
before | 1752.706418988 | 127 | False
before | 1752.716419394 | 113 | False
before | 1752.726421374 | 114 | False
before | 1752.736419927 | 86 | False
before | 1752.746421741 | 121 | False
before | 1752.756431093 | 145 | False
before | 1752.766425331 | 143 | False
before | 1752.776415179 | 85 | False
before | 1752.786418808 | 99 | False
before | 1752.796418547 | 114 | False
before | 1752.806419471 | 111 | False
before | 1752.816418766 | 106 | False
before | 1752.826418171 | 113 | False
before | 1752.836423133 | 114 | False
before | 1752.846426447 | 112 | False
before | 1752.856424056 | 106 | False
before | 1752.866418405 | 136 | False
before | 1752.876416051 | 110 | False
before | 1752.886417661 | 139 | False
before | 1752.896415474 | 100 | False
before | 1752.906418584 | 114 | False
before | 1752.916420786 | 141 | False
before | 1752.926415654 | 129 | False
before | 1752.936419412 | 150 | False
before | 1752.946417762 | 145 | False
before | 1752.95644395 | 95 | False
before | 1752.966430409 | 101 | False
before | 1752.976416609 | 120 | False
before | 1752.986417755 | 124 | False
before | 1752.99642294 | 95 | False
before | 1753.006421642 | 147 | False
before | 1753.016418102 | 132 | False
before | 1753.026418138 | 136 | False
before | 1753.036420636 | 129 | False
before | 1753.046419634 | 125 | False
before | 1753.0564213 | 152 | False
before | 1753.06643167 | 97 | False
before | 1753.076417629 | 93 | False
before | 1753.086418368 | 136 | False
before | 1753.096414496 | 155 | False
before | 1753.106417569 | 140 | False
before | 1753.116419067 | 149 | False
before | 1753.126421251 | 117 | False
before | 1753.136421453 | 116 | False
before | 1753.146428175 | 97 | False
before | 1753.156444731 | 91 | False
before | 1753.166421244 | 118 | False
before | 1753.176419742 | 117 | False
before | 1753.18642113 | 138 | False
before | 1753.196420517 | 130 | False
before | 1753.206416681 | 106 | False
before | 1753.216418735 | 118 | False
before | 1753.226418586 | 121 | False
before | 1753.236420492 | 151 | False
before | 1753.246422509 | 139 | False
output | 1753.256423489 | 84 | False
output | 1753.266430877 | 148 | False
output | 1753.282091789 | 148 | False
output | 1753.286375272 | 125 | False
output | 1753.29662931 | 121 | False
output | 1753.306827115 | 114 | False
output | 1753.316730687 | 128 | False
output | 1753.326854202 | 108 | False
output | 1753.336688744 | 115 | False
output | 1753.346667199 | 108 | False
output | 1753.356681678 | 129 | False
output | 1753.366764909 | 86 | False
output | 1753.376663646 | 127 | False
output | 1753.386666235 | 131 | False
output | 1753.396662285 | 106 | False
output | 1753.406719919 | 116 | False
output | 1753.416663386 | 117 | False
output | 1753.426661233 | 150 | False
output | 1753.436683305 | 149 | False
output | 1753.446660352 | 128 | False
output | 1753.456686907 | 113 | False
output | 1753.466694663 | 127 | False
output | 1753.476662856 | 138 | False
output | 1753.486689411 | 106 | False
output | 1753.496730858 | 123 | False
output | 1753.506669602 | 111 | False
output | 1753.516695083 | 107 | False
output | 1753.526666555 | 118 | False
output | 1753.53666316 | 128 | False
output | 1753.546698698 | 110 | False
output | 1753.556840143 | 114 | False
output | 1753.566745474 | 148 | False
output | 1753.576670012 | 112 | False
output | 1753.586666433 | 124 | False
output | 1753.597072958 | 142 | False
output | 1753.606718098 | 117 | False
output | 1753.616693867 | 135 | False
output | 1753.626686435 | 101 | False
output | 1753.636665741 | 125 | False
output | 1753.646661476 | 117 | False
output | 1753.656688402 | 125 | False
output | 1753.666663782 | 145 | False
output | 1753.676702357 | 146 | False
output | 1753.686728283 | 140 | False
output | 1753.696662767 | 110 | False
output | 1753.706682265 | 131 | False
output | 1753.717031873 | 114 | False
output | 1753.726893549 | 106 | False
output | 1753.736746891 | 114 | False
output | 1753.746660946 | 128 | False
output | 1753.75666646 | 113 | False
output | 1753.766685088 | 118 | False
output | 1753.776668914 | 93 | False
output | 1753.786667742 | 146 | False
output | 1753.796698705 | 127 | False
output | 1753.806690958 | 118 | False
output | 1753.816714291 | 141 | False
output | 1753.826756515 | 141 | False
output | 1753.836668755 | 96 | False
output | 1753.846675195 | 117 | False
output | 1753.856678358 | 112 | False
output | 1753.866661165 | 122 | False
output | 1753.876660345 | 107 | False
output | 1753.886662007 | 138 | False
output | 1753.896697712 | 143 | False
output | 1753.906663405 | 136 | False
output | 1753.916731078 | 127 | False
output | 1753.926707402 | 129 | False
output | 1753.936747533 | 105 | False
output | 1753.946662848 | 143 | False
output | 1753.956666862 | 108 | False
output | 1753.966681563 | 109 | False
output | 1753.976668445 | 131 | False
output | 1753.986692852 | 136 | False
output | 1753.996665176 | 125 | False
output | 1754.006807805 | 80 | False
output | 1754.017060342 | 91 | False
output | 1754.02660754 | 110 | False
output | 1754.036624112 | 132 | False
output | 1754.046864443 | 104 | False
output | 1754.057067935 | 106 | False
output | 1754.066666641 | 100 | False
output | 1754.07669403 | 140 | False
output | 1754.086661723 | 131 | False
output | 1754.09669102 | 134 | False
output | 1754.106663603 | 104 | False
output | 1754.116669988 | 92 | False
output | 1754.126666167 | 133 | False
output | 1754.136692593 | 134 | False
output | 1754.146886416 | 111 | False
output | 1754.157049549 | 106 | False
output | 1754.166660758 | 119 | False
output | 1754.176794701 | 120 | False
output | 1754.186661304 | 74 | False
output | 1754.196667355 | 113 | False
output | 1754.206711358 | 140 | False
output | 1754.216874509 | 116 | False
output | 1754.226670138 | 141 | False
output | 1754.236685691 | 133 | False
output | 1754.246666516 | 141 | False
output | 1754.256813183 | 137 | False
output | 1754.266675767 | 142 | False
output | 1754.276683189 | 125 | False
output | 1754.286658032 | 86 | False
output | 1754.296671768 | 85 | False
output | 1754.306738993 | 98 | False
output | 1754.316740596 | 97 | False
output | 1754.326658908 | 132 | False
output | 1754.33673406 | 140 | False
output | 1754.346667226 | 98 | False
output | 1754.35667459 | 95 | False
output | 1754.366740926 | 110 | False
output | 1754.376743344 | 108 | False
output | 1754.38666023 | 110 | False
output | 1754.396682596 | 114 | False
output | 1754.406665066 | 107 | False
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

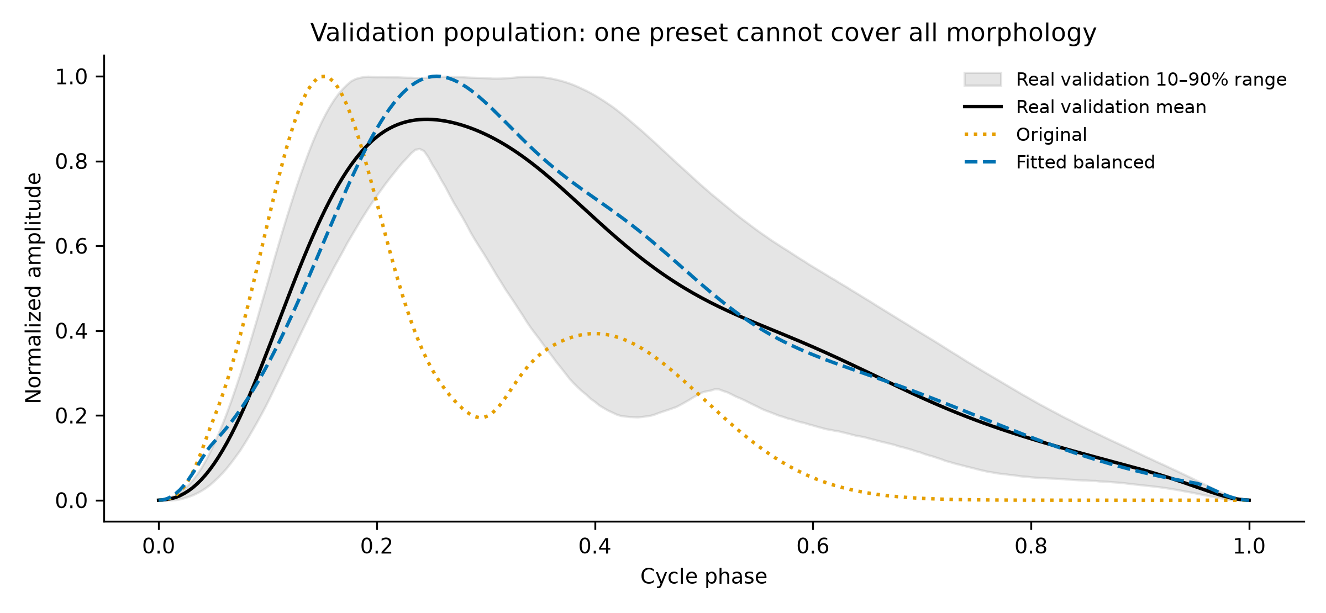
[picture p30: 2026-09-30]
docs/gaussian-fit/validation.png

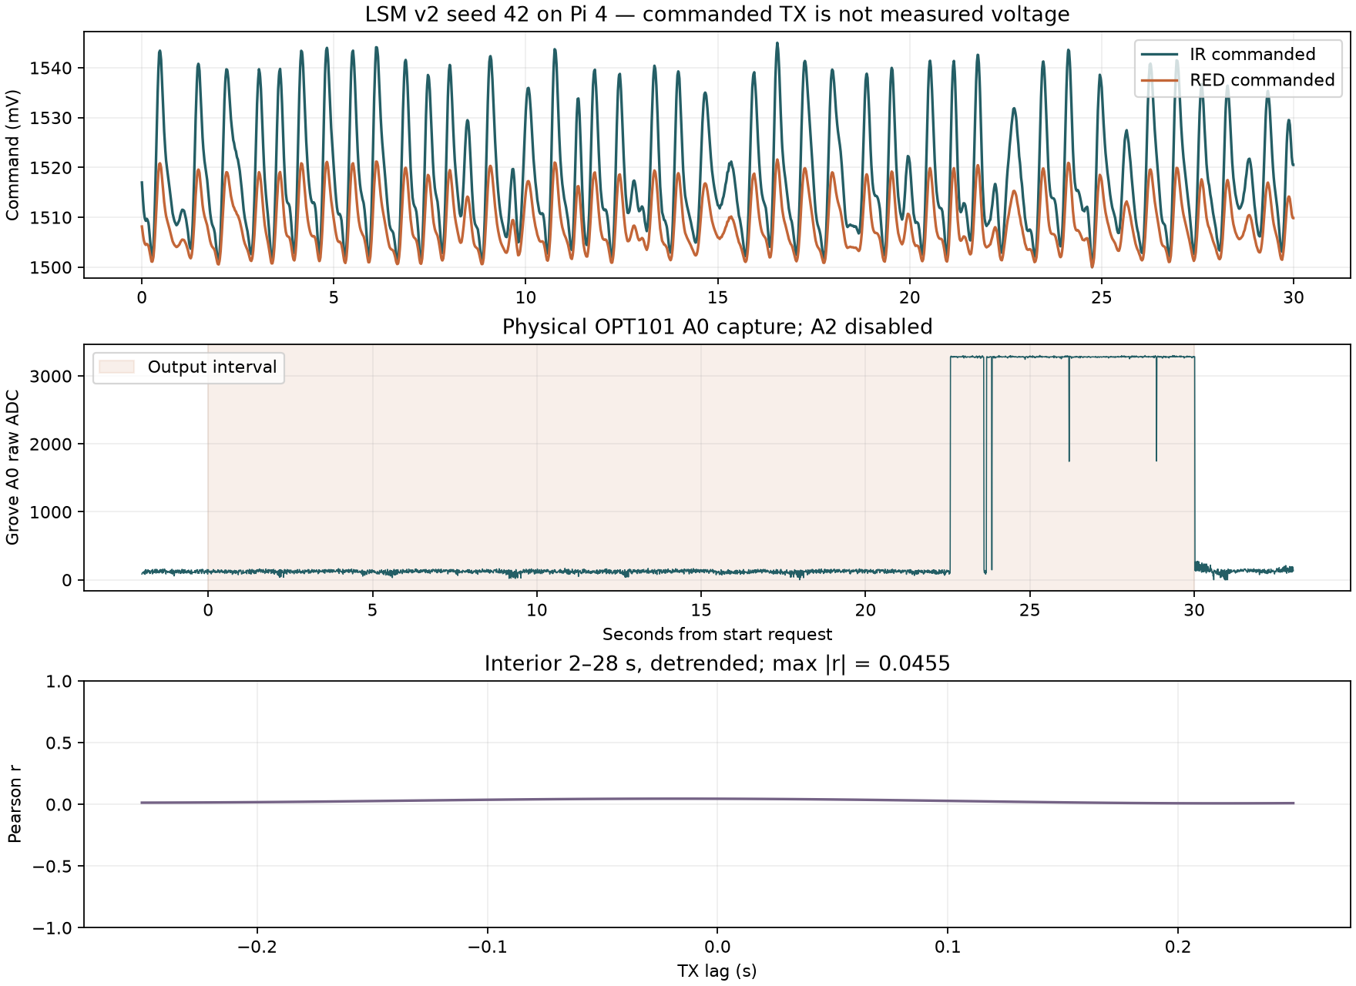
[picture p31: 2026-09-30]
docs/hardware-validation/2026-09-30/timing-fixed/capture.png

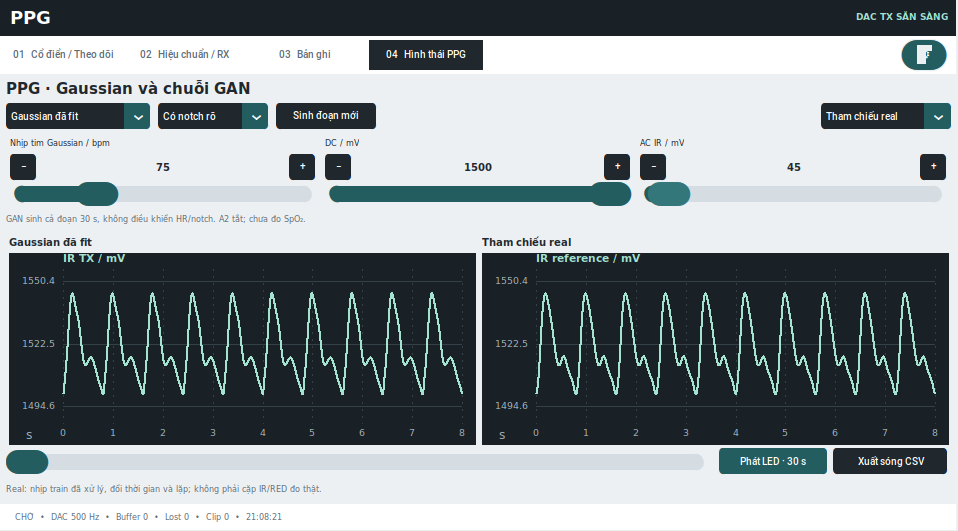
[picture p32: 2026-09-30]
docs/hardware-validation/2026-09-30/app-pi.png

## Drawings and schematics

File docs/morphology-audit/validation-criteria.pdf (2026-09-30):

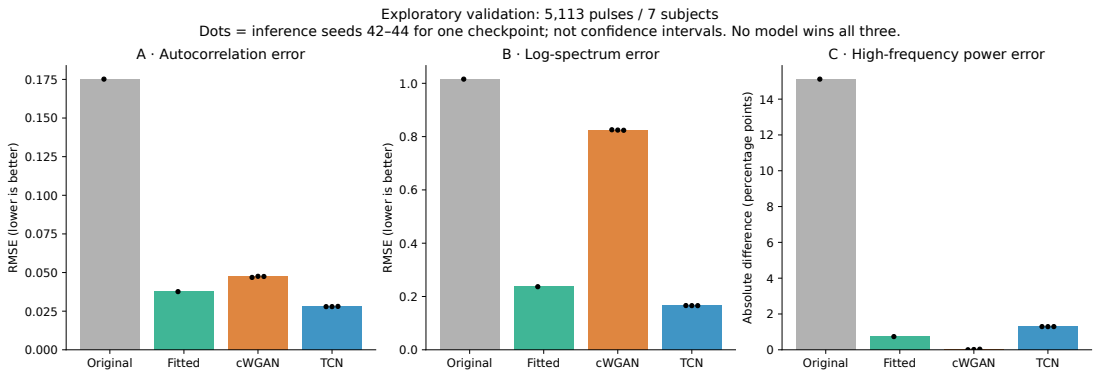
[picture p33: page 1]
Original; Fitted; cWGAN; TCN; A · Autocorrelation error; Absolute di

Exploratory validation: 5,113 pulses / 7 subjects

Dots = inference seeds 42–44 for one checkpoint; not confidence intervals. No model wins all three.

B · Log-spectrum error

C · High-frequency power error

fference (percentage points)

RMSE (lower is better)

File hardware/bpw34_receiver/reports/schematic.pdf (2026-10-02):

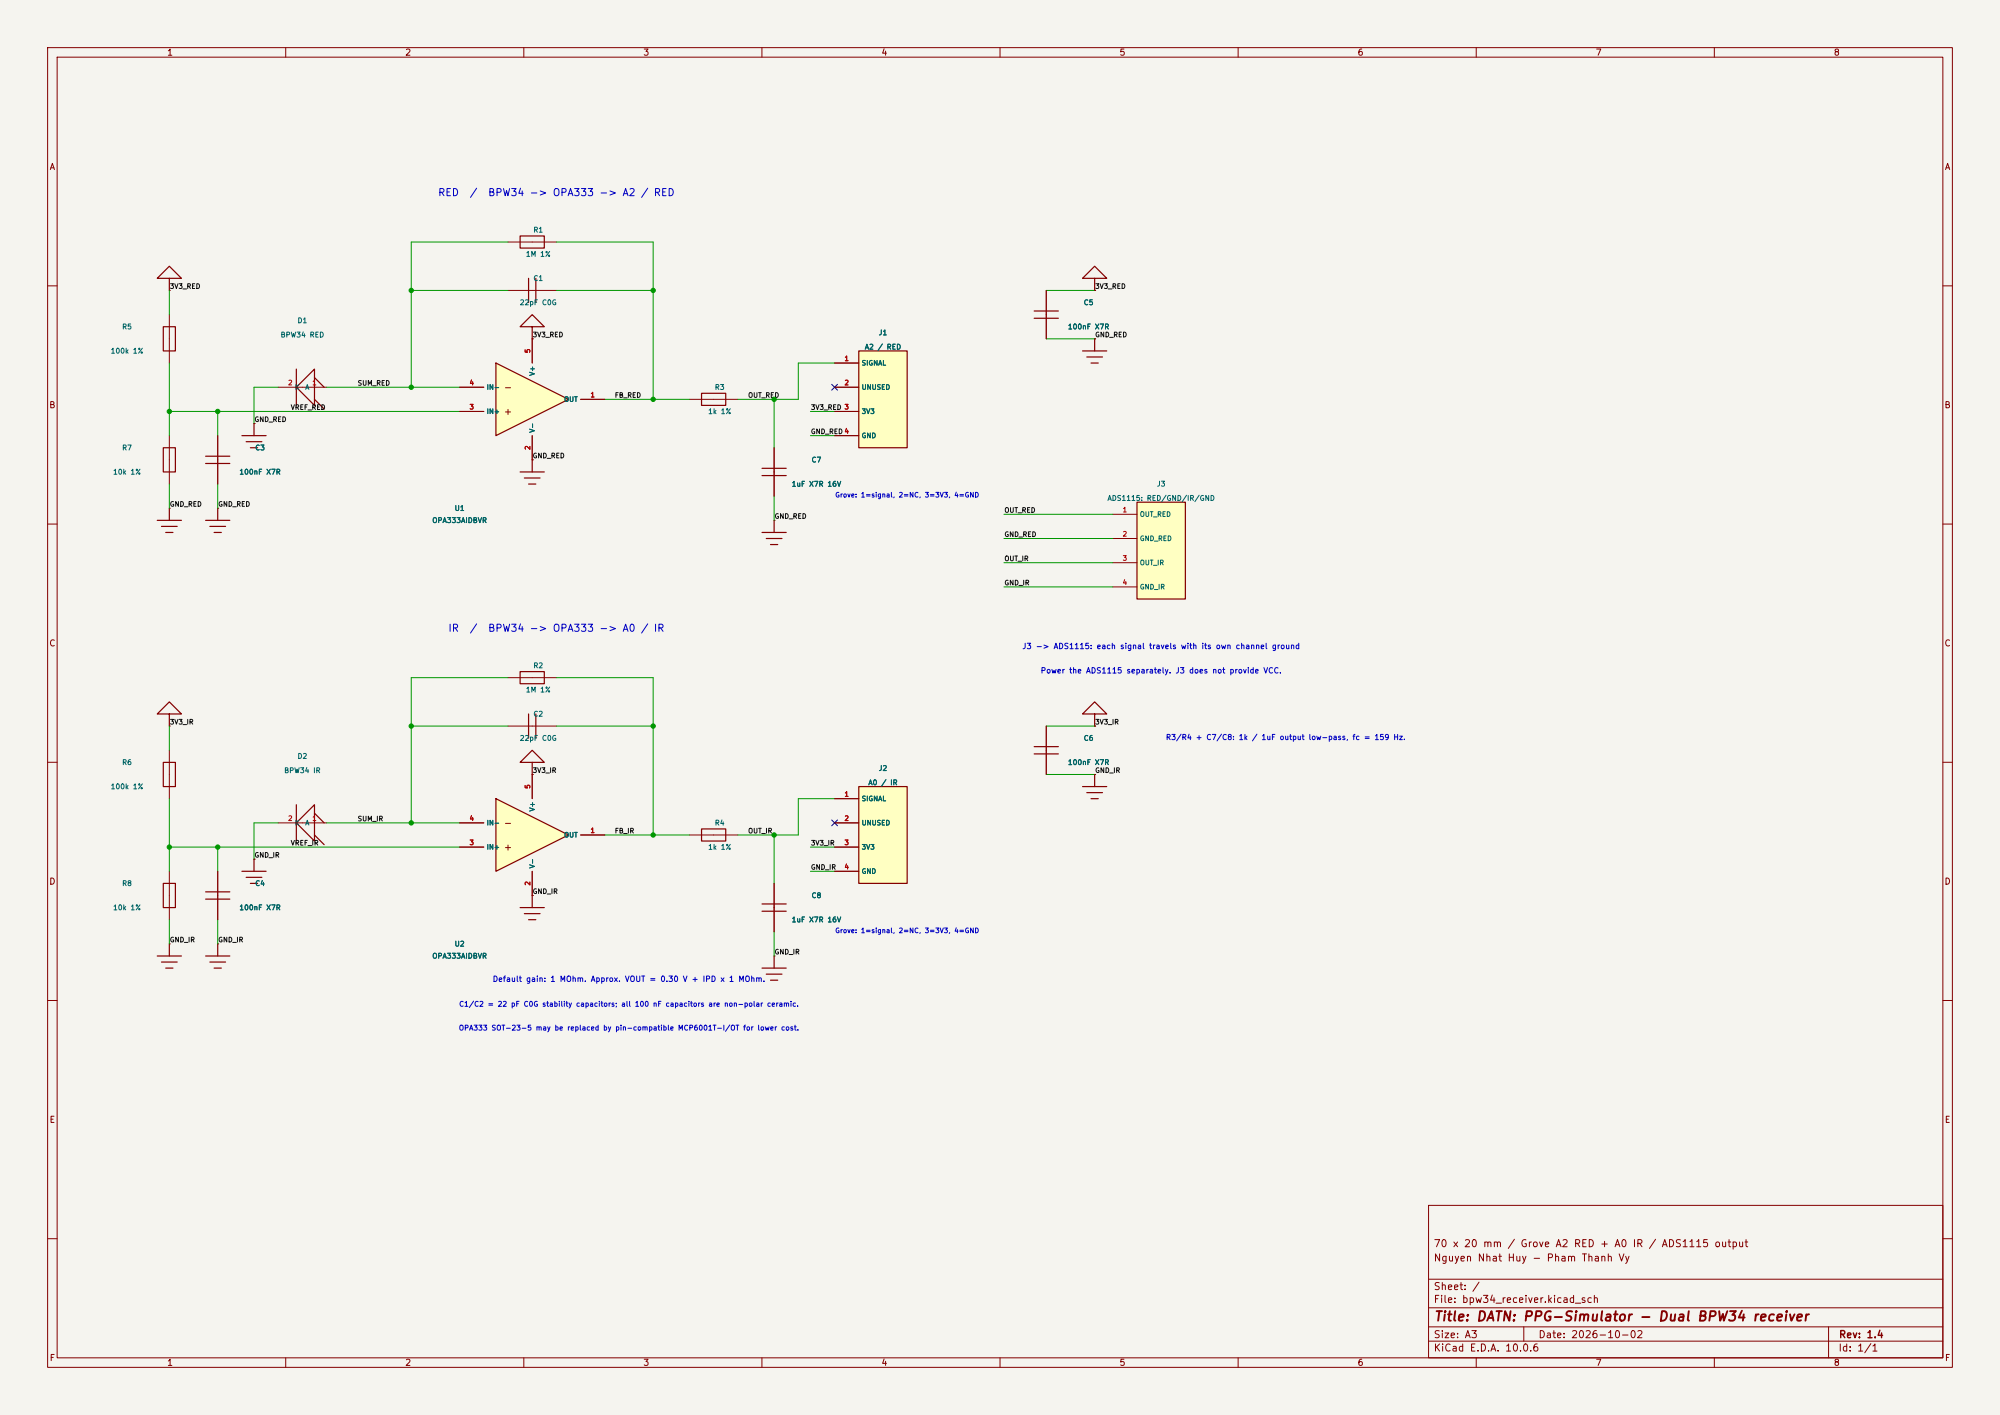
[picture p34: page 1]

ADS1115: RED/GND/IR/GND

Grove: 1=signal, 2=NC, 3=3V3, 4=GND

70 x 20 mm / Grove A2 RED + A0 IR / ADS1115 output
Nguyen Nhat Huy - Pham Thanh Vy

Sheet: /
File: bpw34_receiver.kicad_sch
Title: DATN: PPG-Simulator - Dual BPW34 receiver

Size: A3 | Rev: 1.4 | F Date: 2026-10-02
KiCad E.D.A. 10.0.6 | Id: 1/1

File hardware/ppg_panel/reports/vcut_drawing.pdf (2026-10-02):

## OPT101 RX v1.5 70 x 20 mm

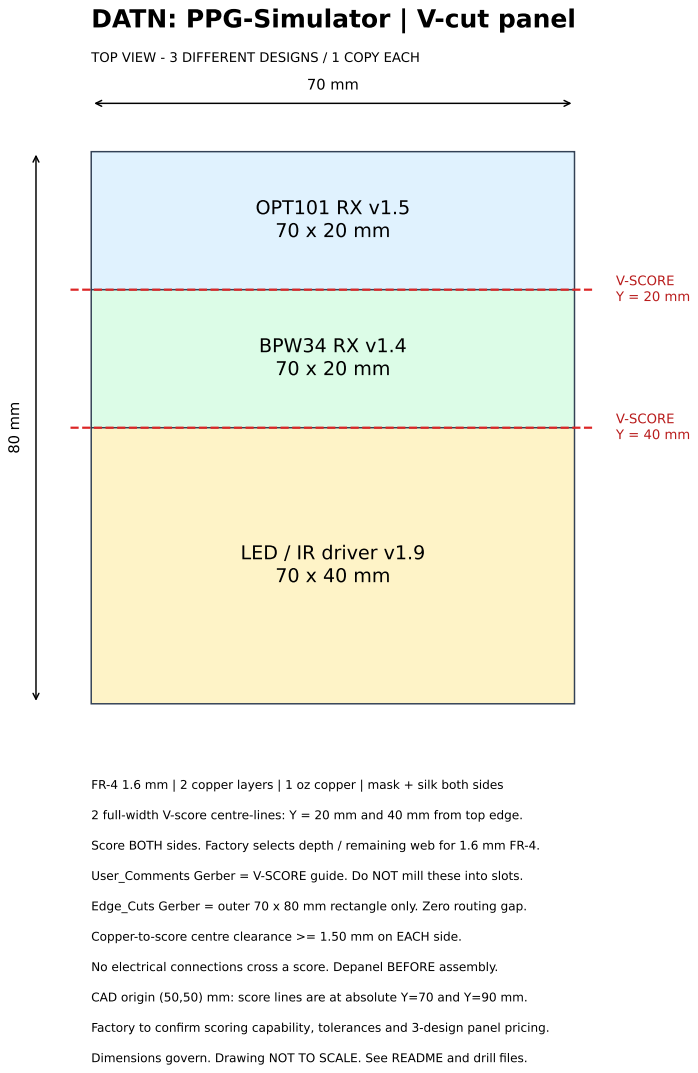
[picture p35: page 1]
BPW34 RX v1.4 70 x 20 mm; V-SCORE Y = 20 mm; V-SCORE Y = 40 mm

DATN: PPG-Simulator | V-cut panel

TOP VIEW - 3 DIFFERENT DESIGNS / 1 COPY EACH

LED / IR driver v1.9

FR-4 1.6 mm | 2 copper layers | 1 oz copper | mask + silk both sides

2 full-width V-score centre-lines: Y = 20 mm and 40 mm from top edge.

Score BOTH sides. Factory selects depth / remaining web for 1.6 mm FR-4.

User_Comments Gerber = V-SCORE guide. Do NOT mill these into slots.

Edge_Cuts Gerber = outer 70 x 80 mm rectangle only. Zero routing gap.

Copper-to-score centre clearance >= 1.50 mm on EACH side.

No electrical connections cross a score. Depanel BEFORE assembly.

CAD origin (50,50) mm: score lines are at absolute Y=70 and Y=90 mm.

Factory to confirm scoring capability, tolerances and 3-design panel pricing.

Dimensions govern. Drawing NOT TO SCALE. See README and drill files.

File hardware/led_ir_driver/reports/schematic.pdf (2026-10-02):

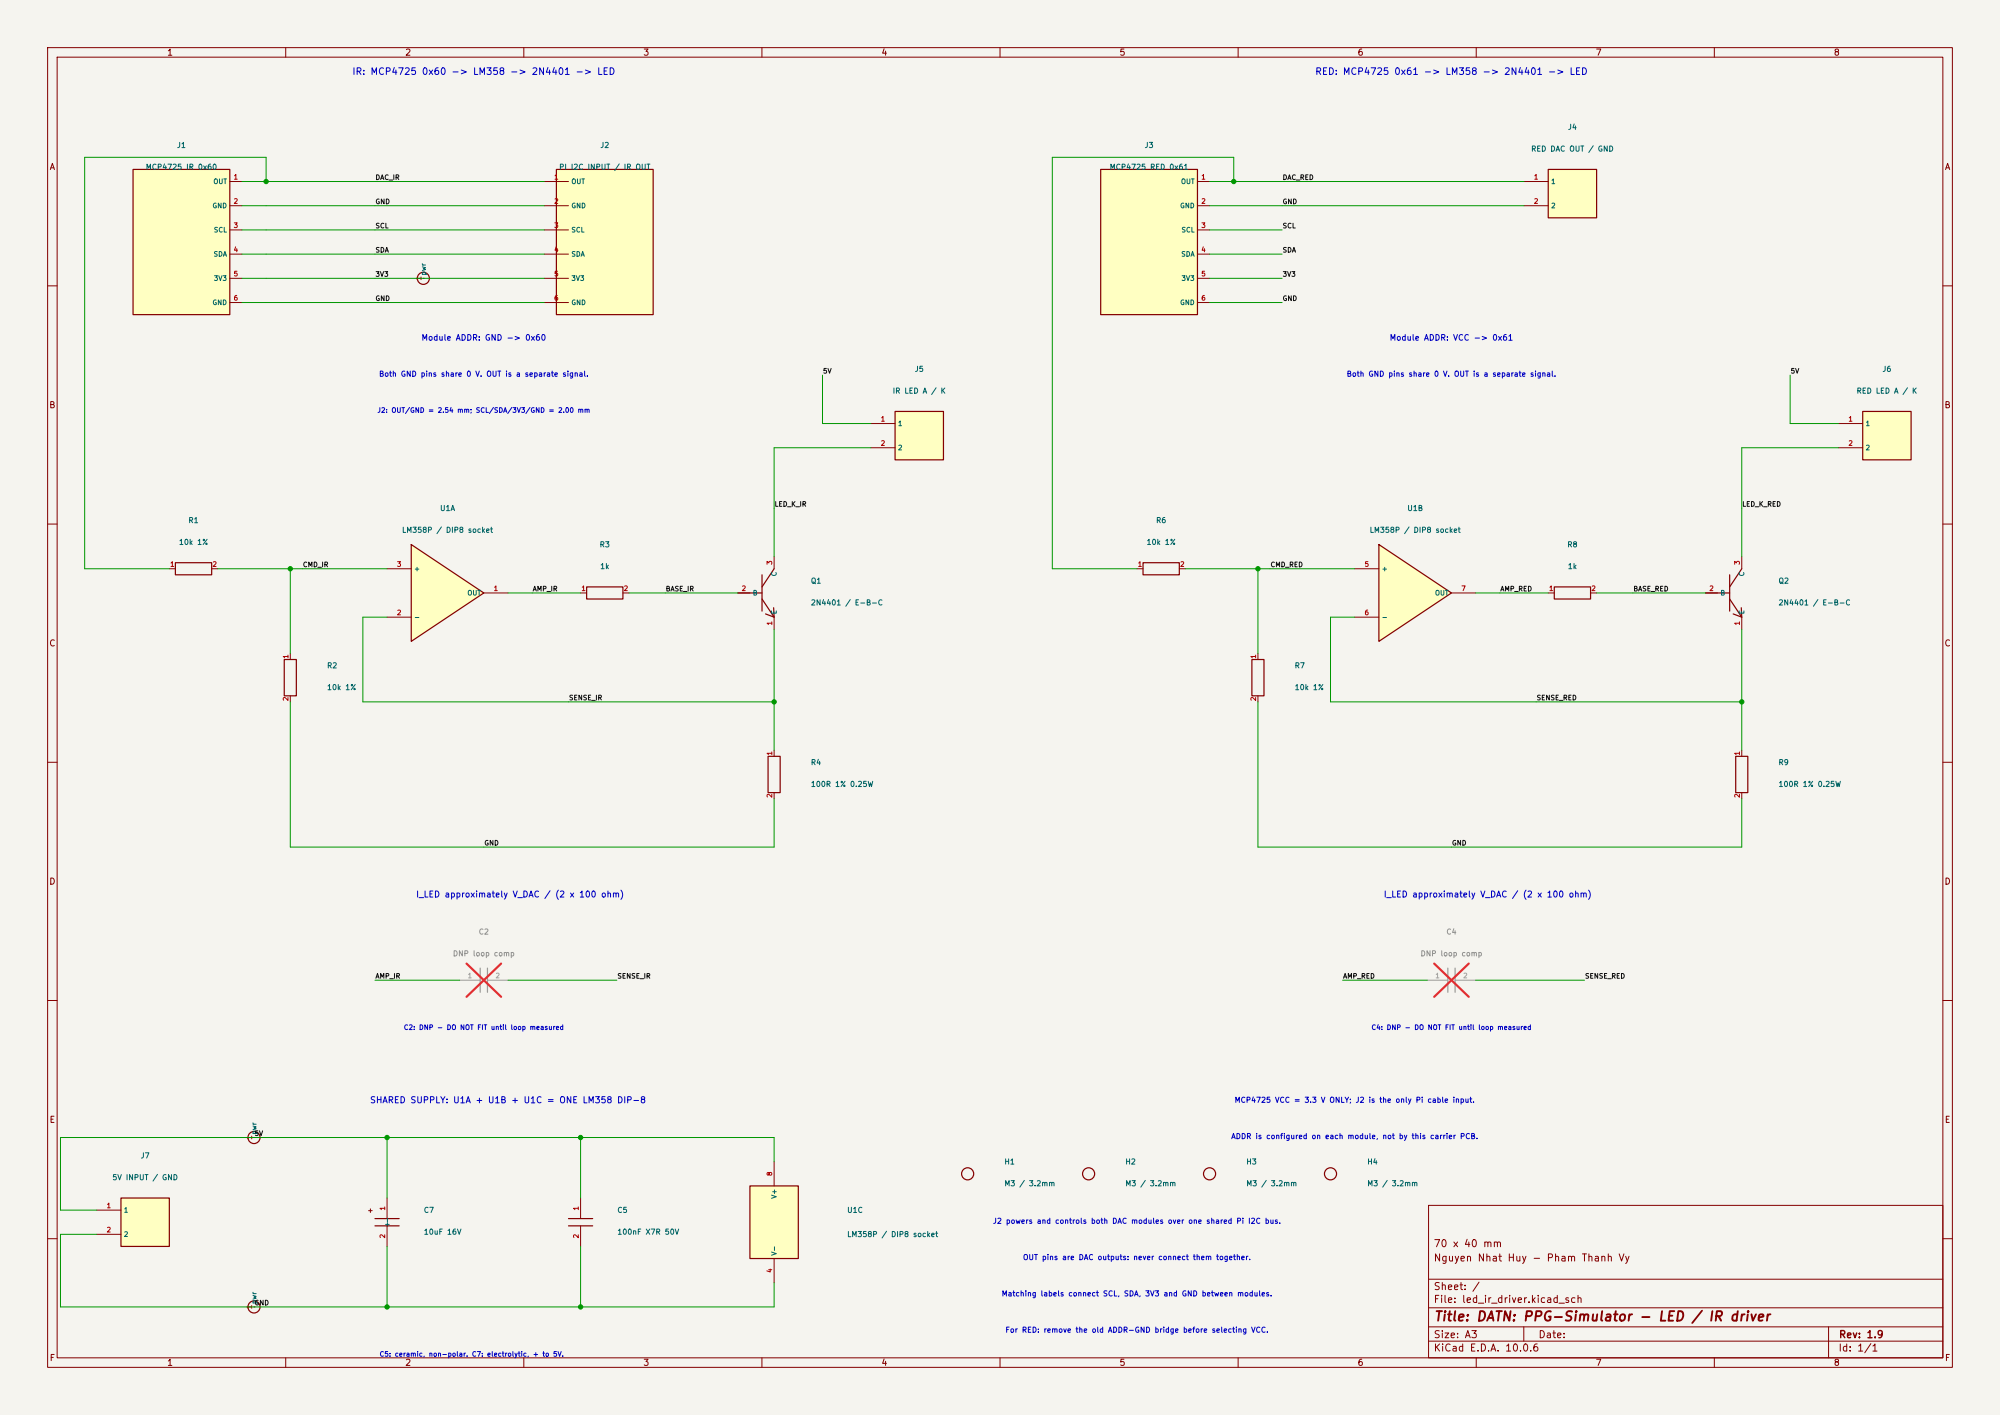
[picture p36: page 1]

J4 RED DAC OUT / GND

J2 PI I2C INPUT / IR OUT

Both GND pins share 0 V. OUT is a separate signal.

C2: DNP - DO NOT FIT until loop measured

SHARED SUPPLY: U1A + U1B + U1C = ONE LM358 DIP-8

ADDR is configured on each module, not by this carrier PCB. MCP4725 VCC = 3.3 V ONLY; J2 is the only Pi cable input.

For RED: remove the old ADDR-GND bridge before selecting VCC. Matching labels connect SCL, SDA, 3V3 and GND between modules. OUT pins are DAC outputs: never connect them together. J2 powers and controls both DAC modules over one shared Pi I2C bus.

Nguyen Nhat Huy - Pham Thanh Vy

Sheet: /
File: led_ir_driver.kicad_sch
Title: DATN: PPG-Simulator - LED / IR driver

Size: A3 | Rev: 1.9 | F Date:
KiCad E.D.A. 10.0.6 | Id: 1/1

C5: ceramic, non-polar. C7: electrolytic, + to 5V.

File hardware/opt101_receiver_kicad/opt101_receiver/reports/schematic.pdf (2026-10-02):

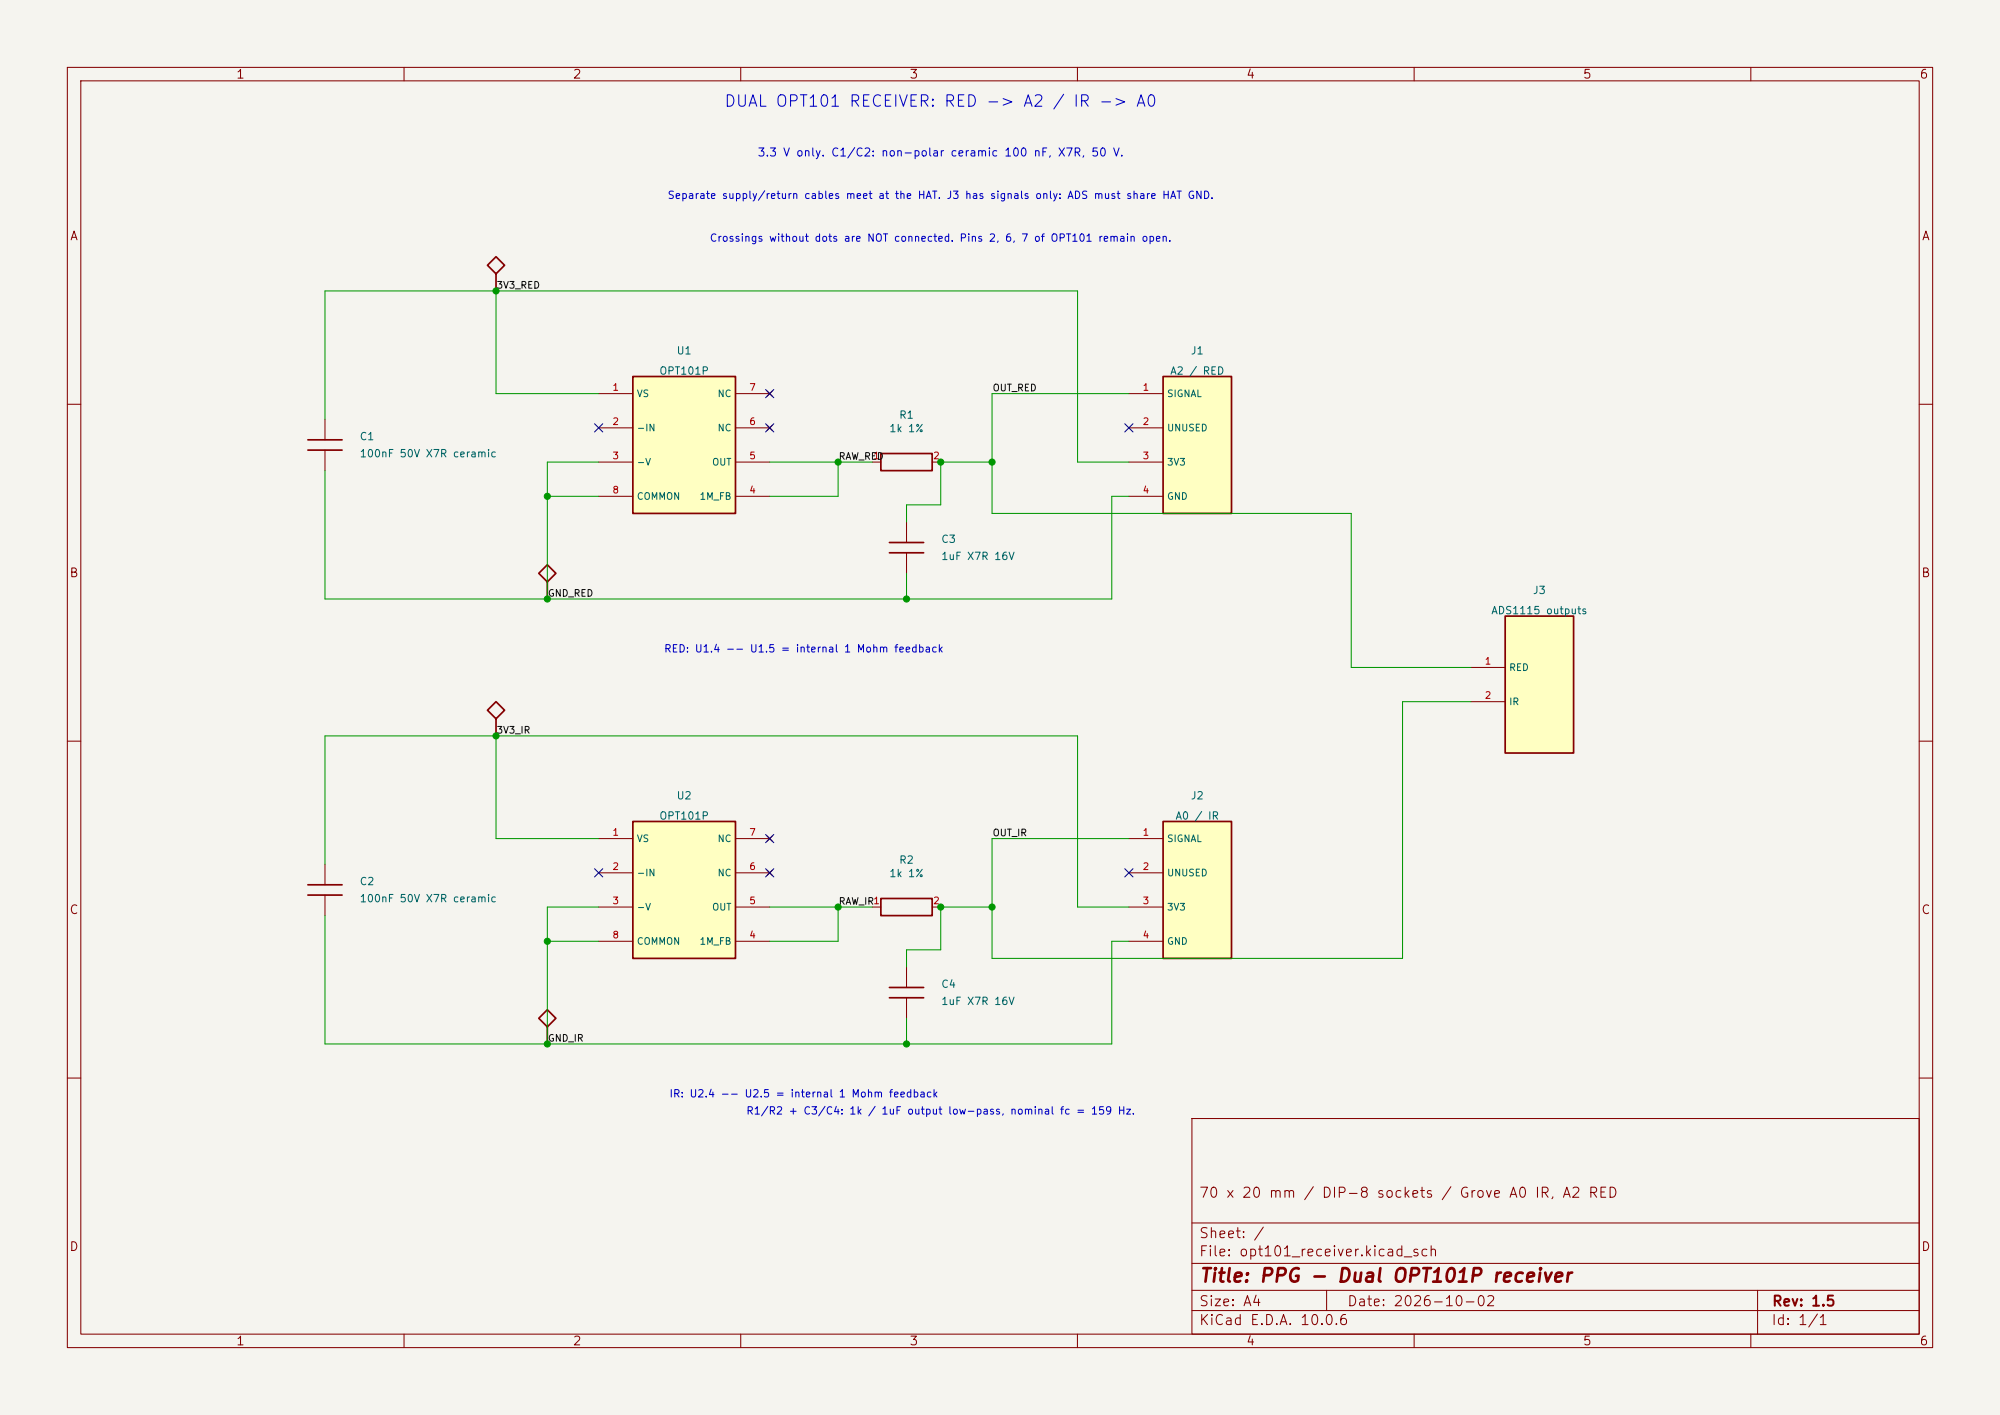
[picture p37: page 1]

DUAL OPT101 RECEIVER: RED -> A2 / IR -> A0

3.3 V only. C1/C2: non-polar ceramic 100 nF, X7R, 50 V. Separate supply/return cables meet at the HAT. J3 has signals only: ADS must share HAT GND. Crossings without dots are NOT connected. Pins 2, 6, 7 of OPT101 remain open. RED: U1.4 -- U1.5 = internal 1 Mohm feedback

RAW_RED R1/R2 + C3/C4: 1k / 1uF output low-pass, nominal fc = 159 Hz.

IR: U2.4 -- U2.5 = internal 1 Mohm feedback

70 x 20 mm / DIP-8 sockets / Grove A0 IR, A2 RED

Sheet: /
File: opt101_receiver.kicad_sch
Title: PPG - Dual OPT101P receiver

Size: A4 | Rev: 1.5
KiCad E.D.A. 10.0.6 | Id: 1/1

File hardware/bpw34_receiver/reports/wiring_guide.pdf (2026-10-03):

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

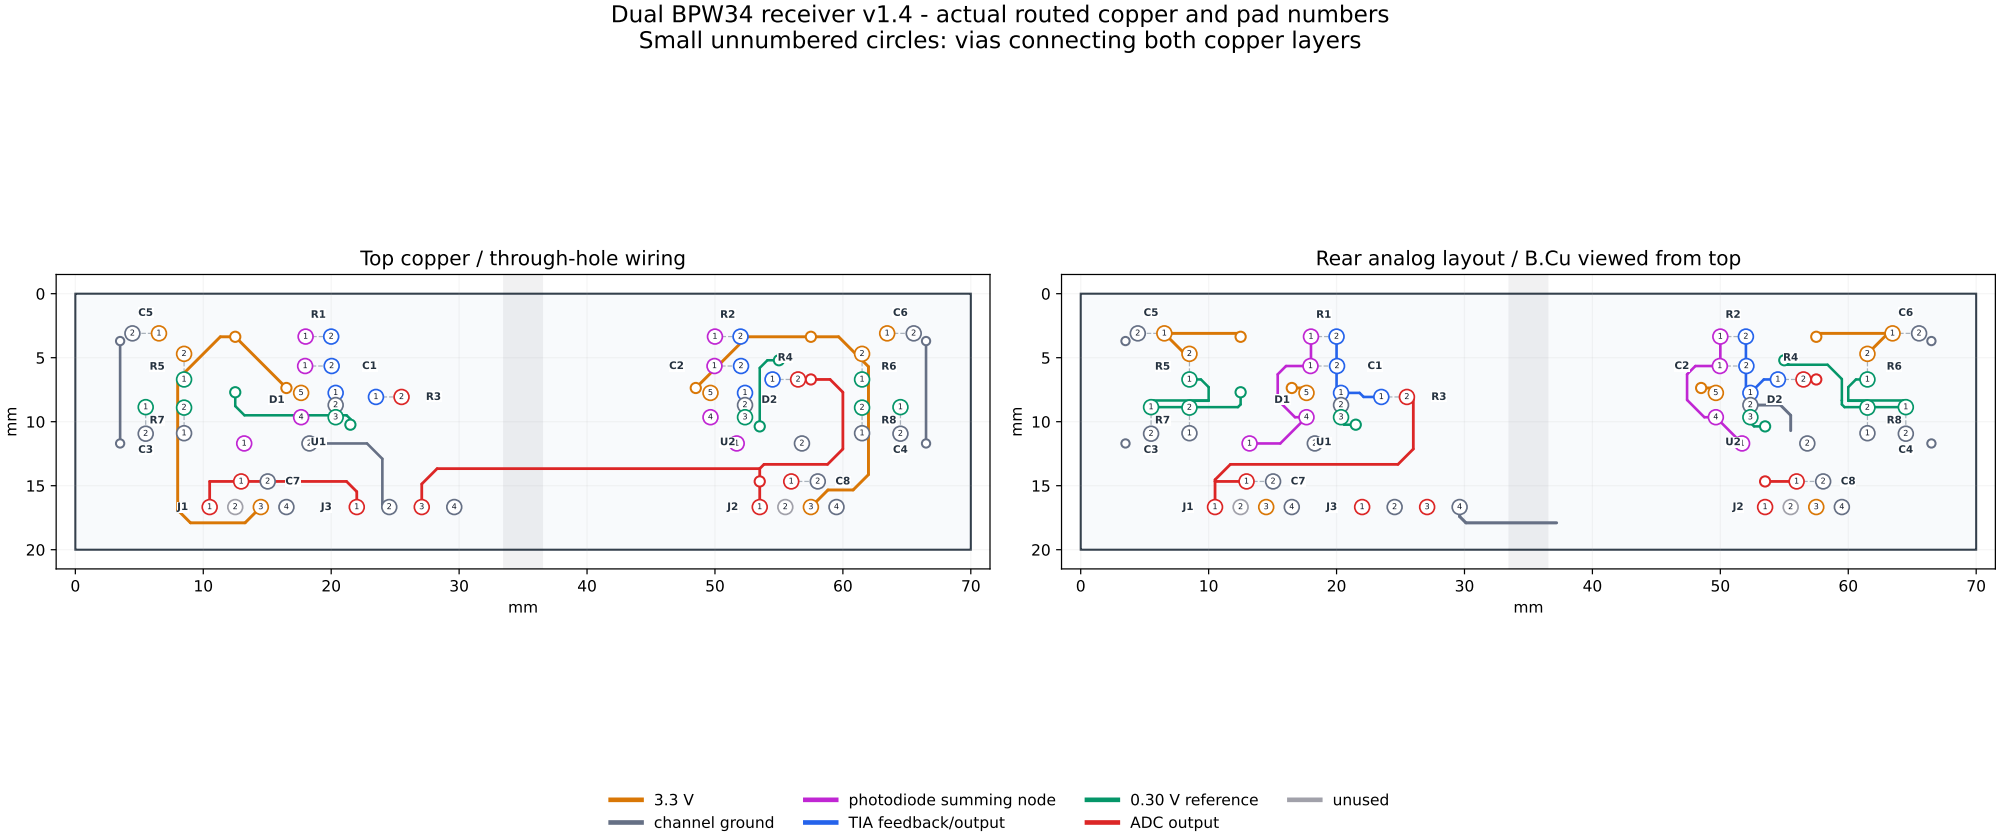
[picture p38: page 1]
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

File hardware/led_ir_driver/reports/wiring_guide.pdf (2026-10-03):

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

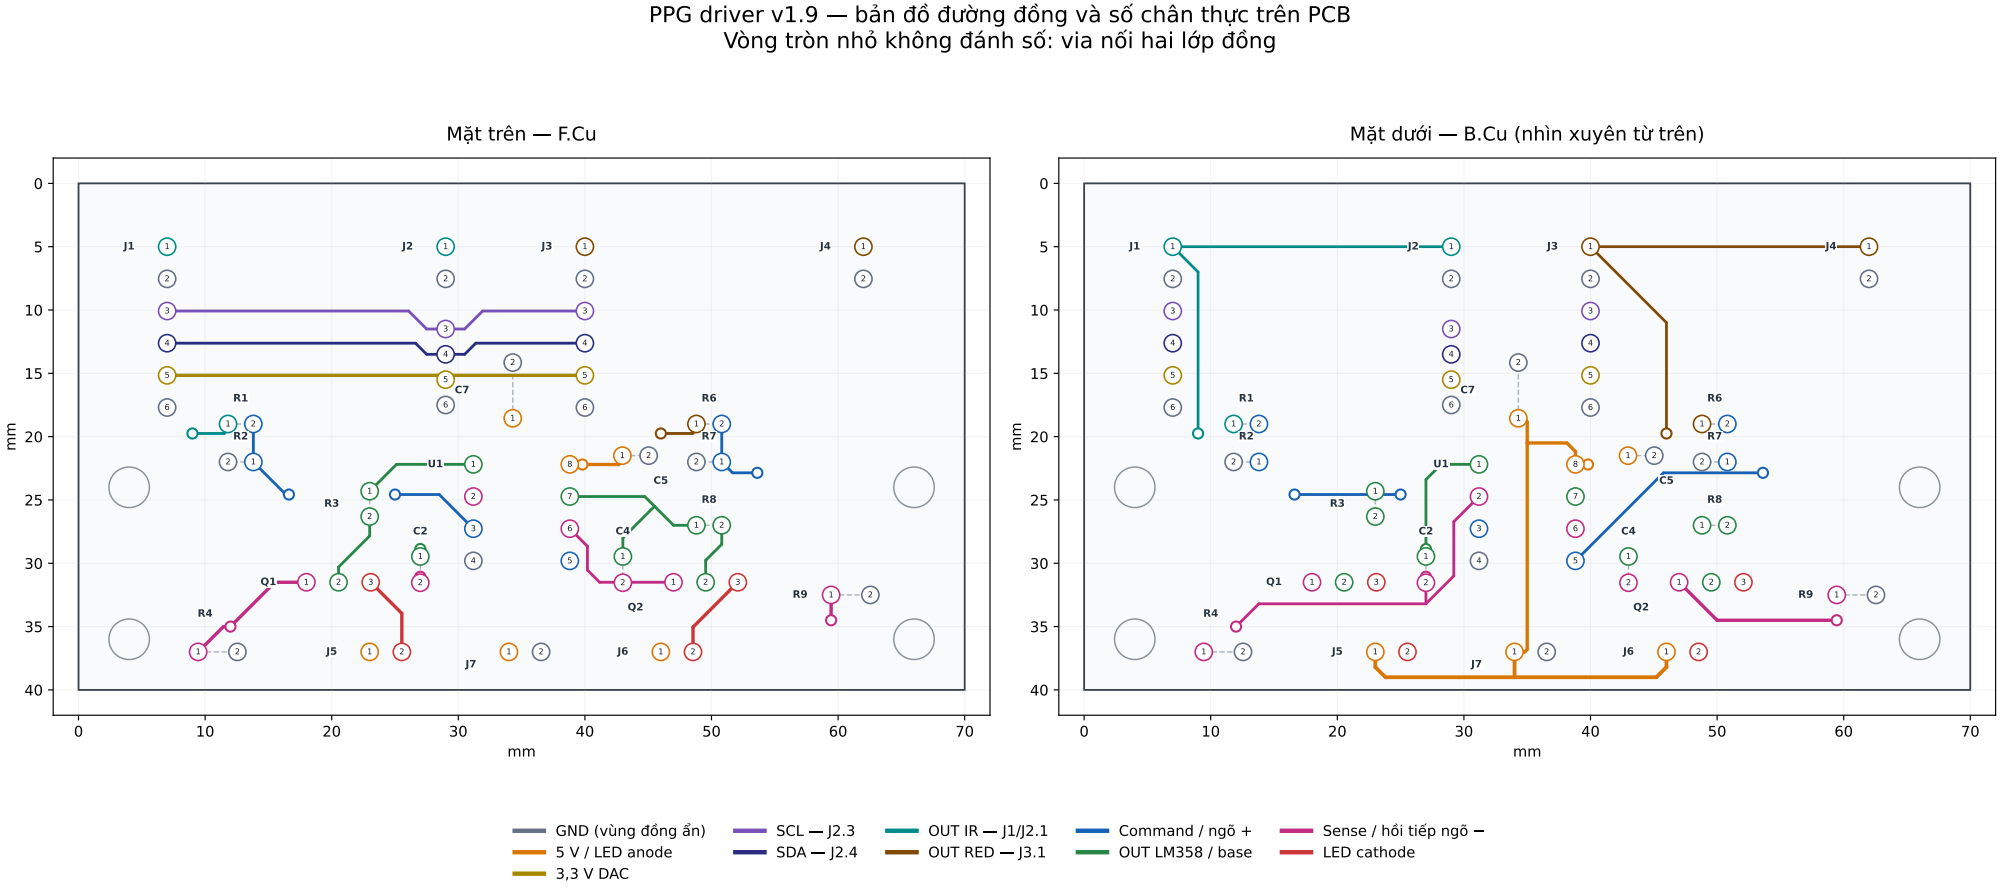
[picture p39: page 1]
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

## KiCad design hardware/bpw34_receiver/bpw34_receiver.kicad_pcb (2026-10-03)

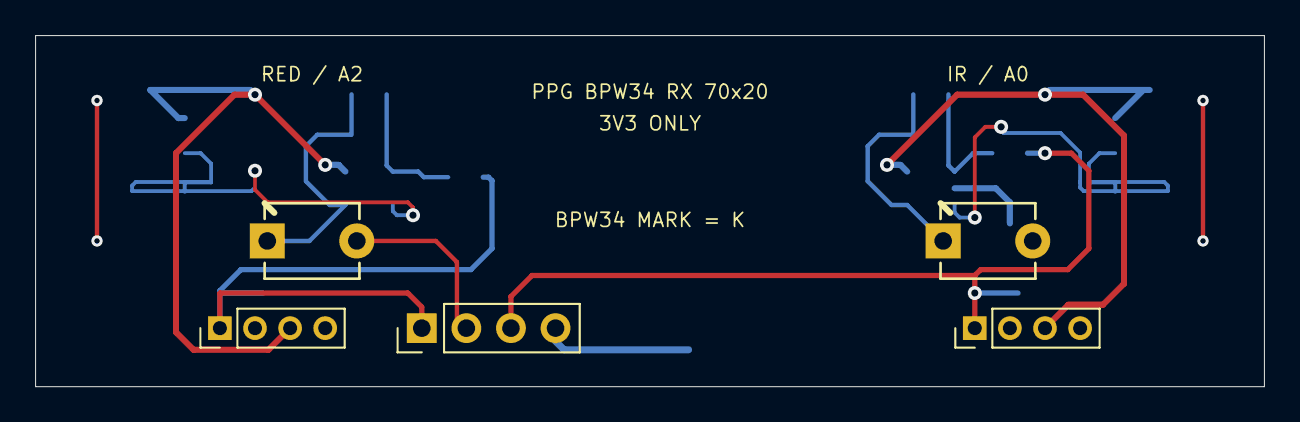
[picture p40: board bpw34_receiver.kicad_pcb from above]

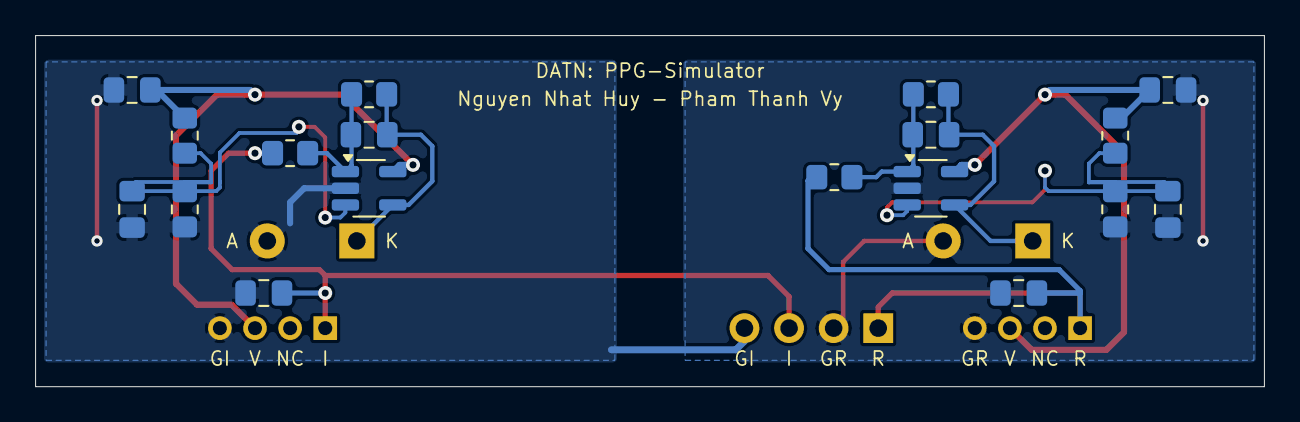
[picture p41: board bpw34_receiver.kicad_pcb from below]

Board: 2 copper layers, 70.0 x 20.0 mm, 23 parts (18 on the bottom side), 12 nets.

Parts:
C1, C2: 22pF C0G; C0805_Hand
C3, C4, C5, C6: 100nF X7R; C0805_Hand
C7, C8: 1uF X7R 16V; C0805_Hand
D1: BPW34 RED; BPW34_THT
D2: BPW34 IR; BPW34_THT
J1: A2 / RED; Header_1x04_P2mm
J2: A0 / IR; Header_1x04_P2mm
J3: ADS1115: RED/GND/IR/GND; Header_1x04_P2.54mm
R1, R2: 1M 1%; R0805_Hand
R3, R4: 1k 1%; R0805_Hand
R5, R6: 100k 1%; R0805_Hand
R7, R8: 10k 1%; R0805_Hand
U1, U2: OPA333AIDBVR; SOT23_5_Hand

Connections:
/3V3_IR: C6.1, J2.3, R6.2, U2.5
/3V3_RED: C5.1, J1.3, R5.2, U1.5
/FB_IR: C2.2, R2.2, R4.1, U2.1
/FB_RED: C1.2, R1.2, R3.1, U1.1
/GND_IR: C4.2, C6.2, C8.2, D2.2, J2.4, J3.4, R8.1, U2.2
/GND_RED: C3.2, C5.2, C7.2, D1.2, J1.4, J3.2, R7.1, U1.2
/OUT_IR: C8.1, J2.1, J3.3, R4.2
/OUT_RED: C7.1, J1.1, J3.1, R3.2
/SUM_IR: C2.1, D2.1, R2.1, U2.4
/SUM_RED: C1.1, D1.1, R1.1, U1.4
/VREF_IR: C4.1, R6.1, R8.2, U2.3
/VREF_RED: C3.1, R5.1, R7.2, U1.3

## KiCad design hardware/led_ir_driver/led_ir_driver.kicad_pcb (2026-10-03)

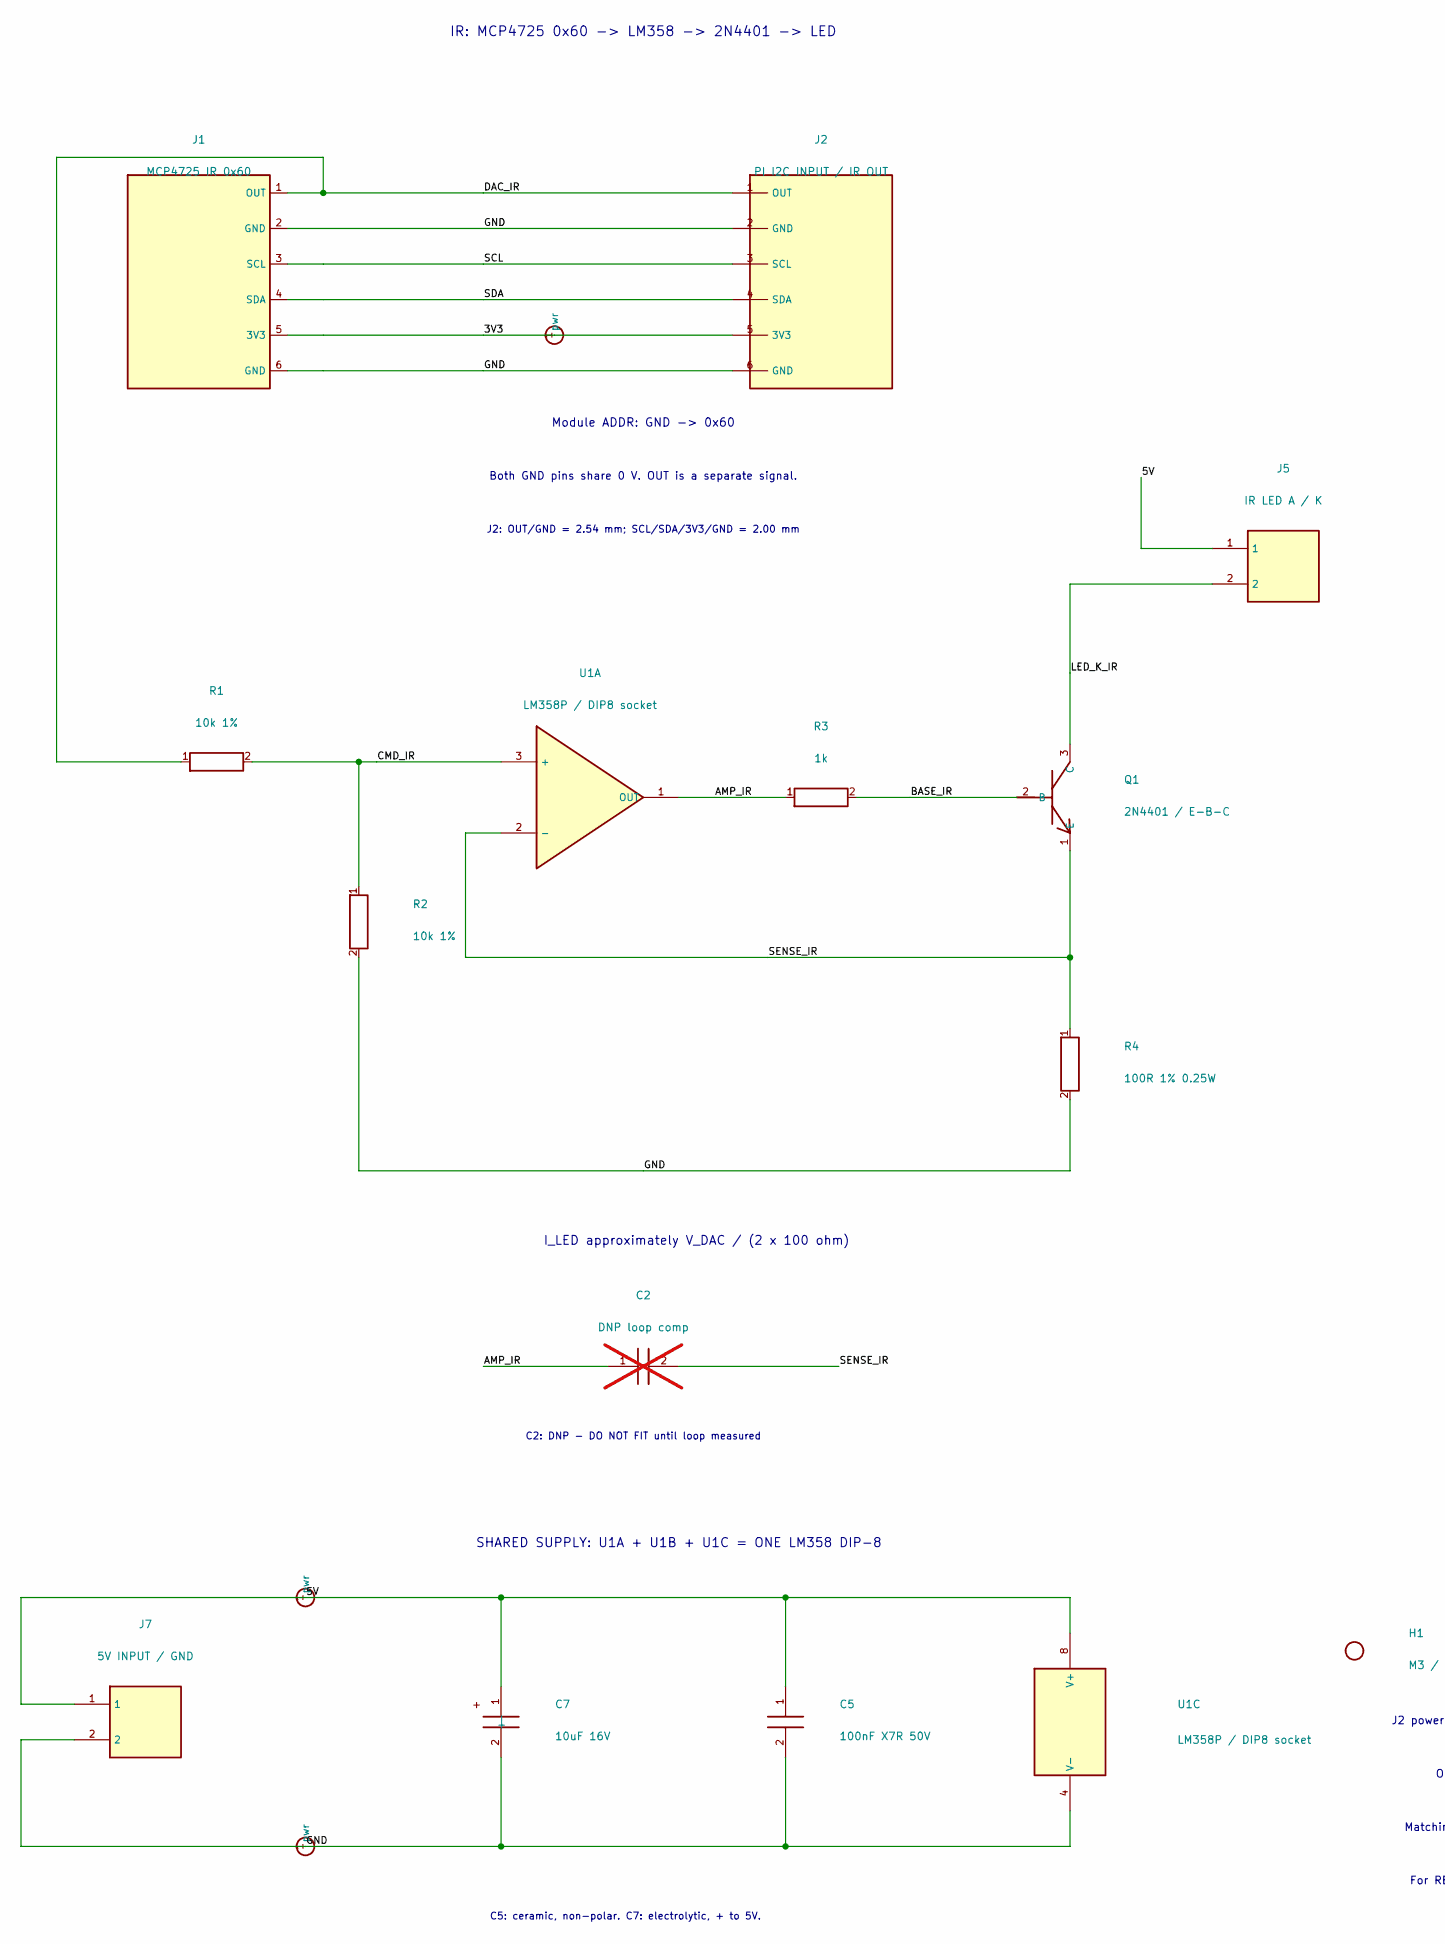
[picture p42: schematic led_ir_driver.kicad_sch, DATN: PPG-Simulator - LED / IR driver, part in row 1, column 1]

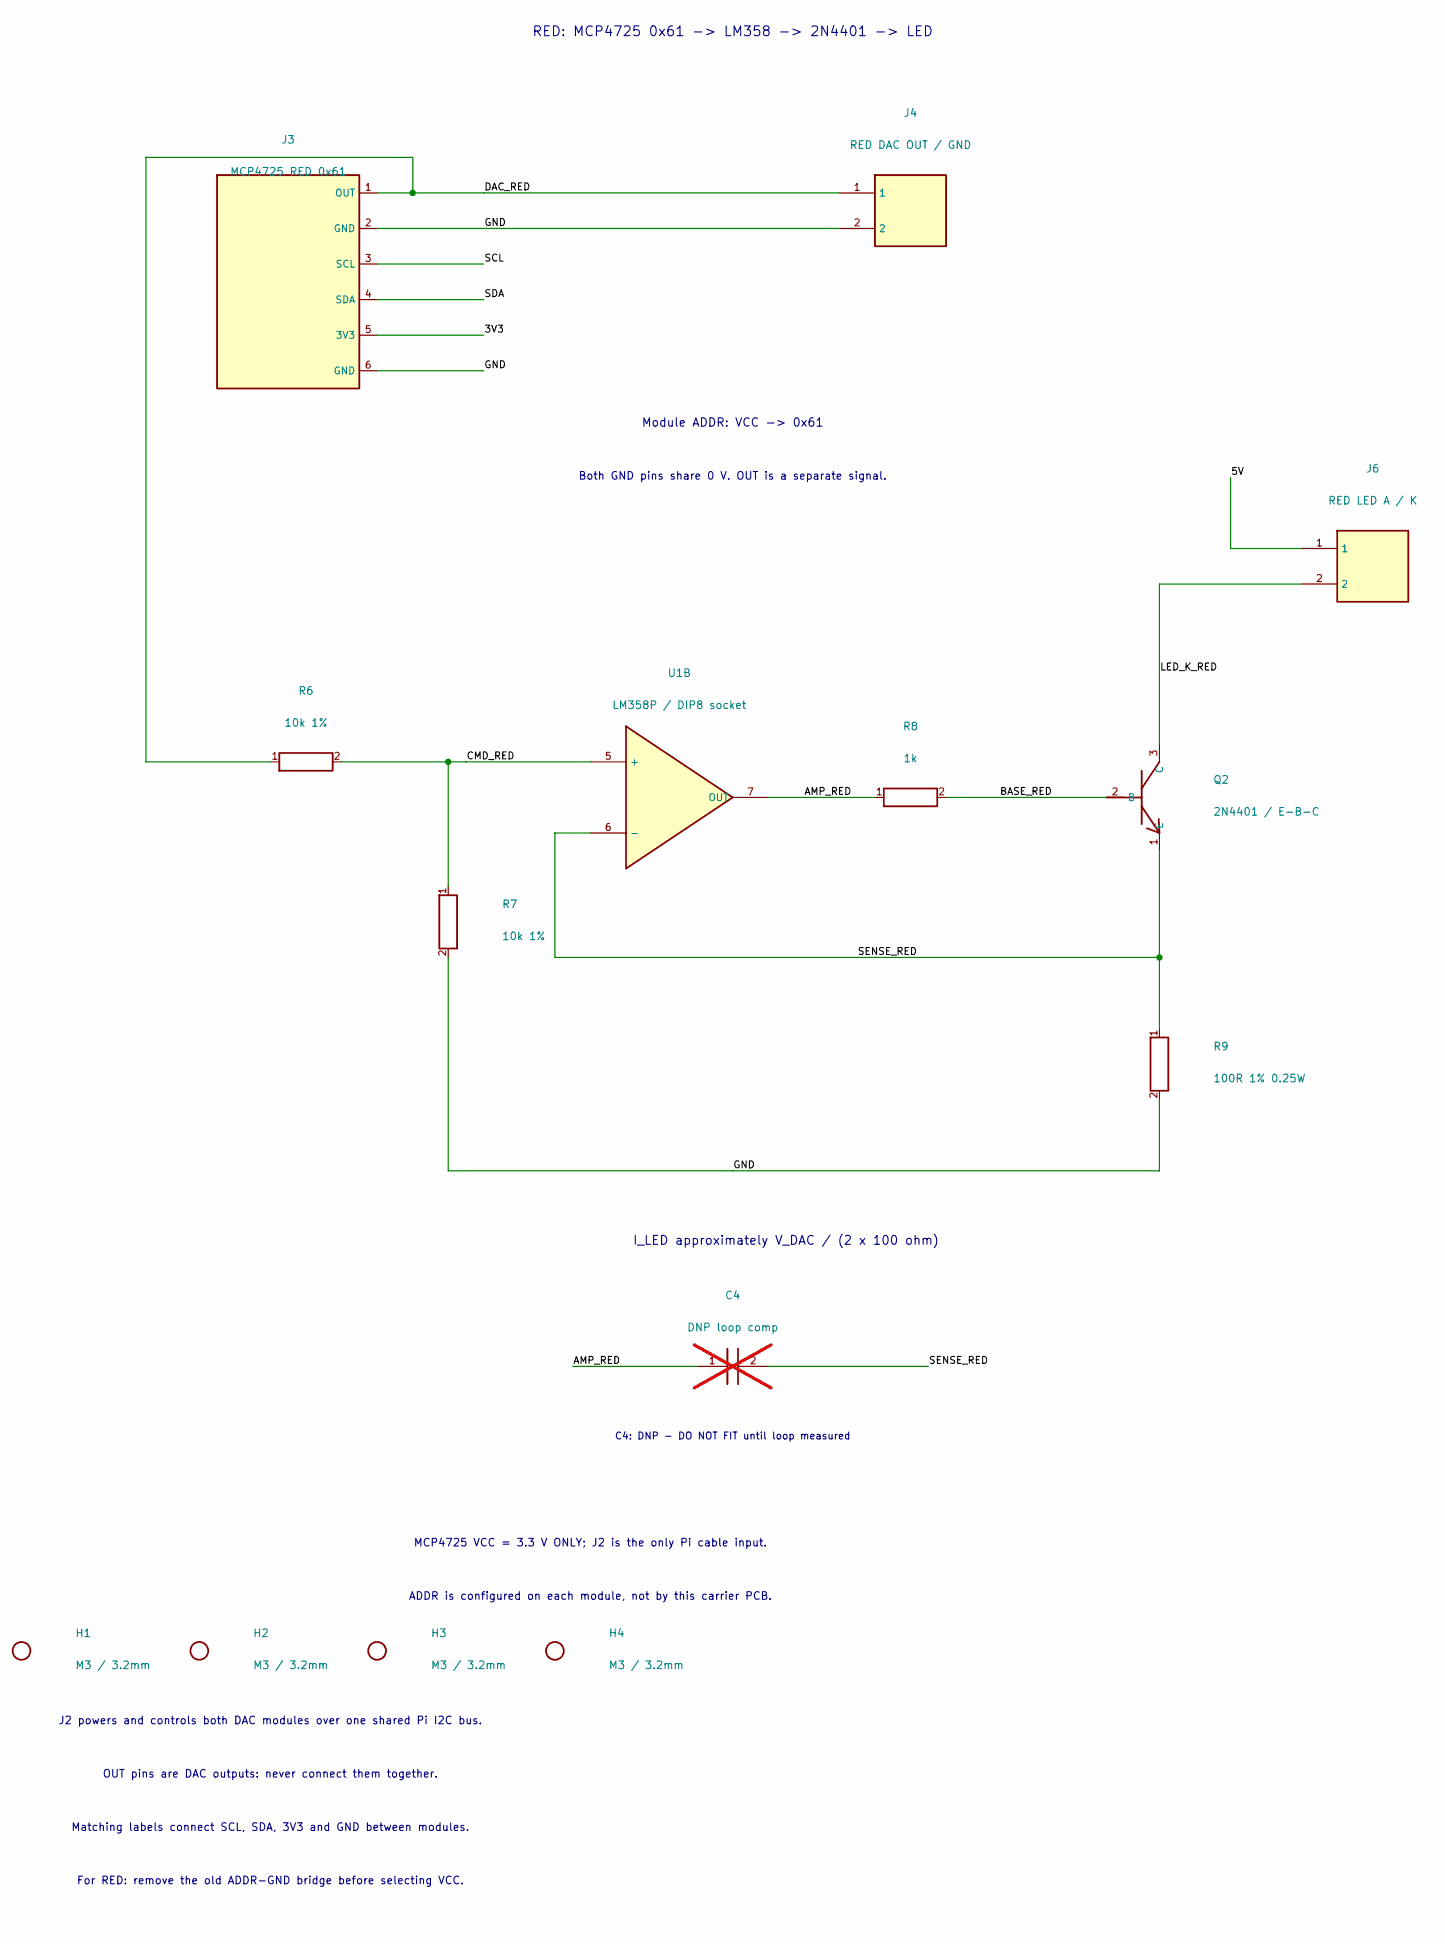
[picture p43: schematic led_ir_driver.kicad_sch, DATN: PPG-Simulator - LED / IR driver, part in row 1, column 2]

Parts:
C2, C4: DNP loop comp; C; not fitted
C5: 100nF X7R 50V; C
C7: 10uF 16V; CP
H1, H2, H3, H4: M3 / 3.2mm; Hole
J1: MCP4725 IR 0x60; Socket6
J2: PI I2C INPUT / IR OUT; HeaderMixed
J3: MCP4725 RED 0x61; Socket6
J4: RED DAC OUT / GND; Header2
J5: IR LED A / K; Header2
J6: RED LED A / K; Header2
J7: 5V INPUT / GND; Header2
Q1, Q2: 2N4401 / E-B-C; NPN
R1, R2, R6, R7: 10k 1%; R
R3, R8: 1k; R
R4, R9: 100R 1% 0.25W; RSense
U1: LM358P / DIP8 socket; DIP8

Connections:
/3V3: J1.5 (3V3), J2.5 (3V3), J3.5 (3V3)
/5V: C5.1, C7.1 (+), J5.1, J6.1, J7.1, U1.8 (V+)
/AMP_IR: C2.1, R3.1, U1.1 (OUT)
/AMP_RED: C4.1, R8.1, U1.7 (OUT)
/BASE_IR: Q1.2 (B), R3.2
/BASE_RED: Q2.2 (B), R8.2
/CMD_IR: R1.2, R2.1, U1.3 (+)
/CMD_RED: R6.2, R7.1, U1.5 (+)
/DAC_IR: J1.1 (OUT), J2.1 (OUT), R1.1
/DAC_RED: J3.1 (OUT), J4.1, R6.1
/GND: C5.2, C7.2 (-), J1.2 (GND), J1.6 (GND), J2.2 (GND), J2.6 (GND), J3.2 (GND), J3.6 (GND), J4.2, J7.2, R2.2, R4.2, R7.2, R9.2, U1.4 (V-)
/LED_K_IR: J5.2, Q1.3 (C)
/LED_K_RED: J6.2, Q2.3 (C)
/SCL: J1.3 (SCL), J2.3 (SCL), J3.3 (SCL)
/SDA: J1.4 (SDA), J2.4 (SDA), J3.4 (SDA)
/SENSE_IR: C2.2, Q1.1 (E), R4.1, U1.2 (-)
/SENSE_RED: C4.2, Q2.1 (E), R9.1, U1.6 (-)

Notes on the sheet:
IR: MCP4725 0x60 -> LM358 -> 2N4401 -> LED
Module ADDR: GND -> 0x60
Both GND pins share 0 V. OUT is a separate signal.
J2: OUT/GND = 2.54 mm; SCL/SDA/3V3/GND = 2.00 mm
I_LED approximately V_DAC / (2 x 100 ohm)
C2: DNP - DO NOT FIT until loop measured
RED: MCP4725 0x61 -> LM358 -> 2N4401 -> LED
Module ADDR: VCC -> 0x61
C4: DNP - DO NOT FIT until loop measured
SHARED SUPPLY: U1A + U1B + U1C = ONE LM358 DIP-8
C5: ceramic, non-polar. C7: electrolytic, + to 5V.
MCP4725 VCC = 3.3 V ONLY; J2 is the only Pi cable input.
ADDR is configured on each module, not by this carrier PCB.
J2 powers and controls both DAC modules over one shared Pi I2C bus.
OUT pins are DAC outputs: never connect them together.
Matching labels connect SCL, SDA, 3V3 and GND between modules.
For RED: remove the old ADDR-GND bridge before selecting VCC.

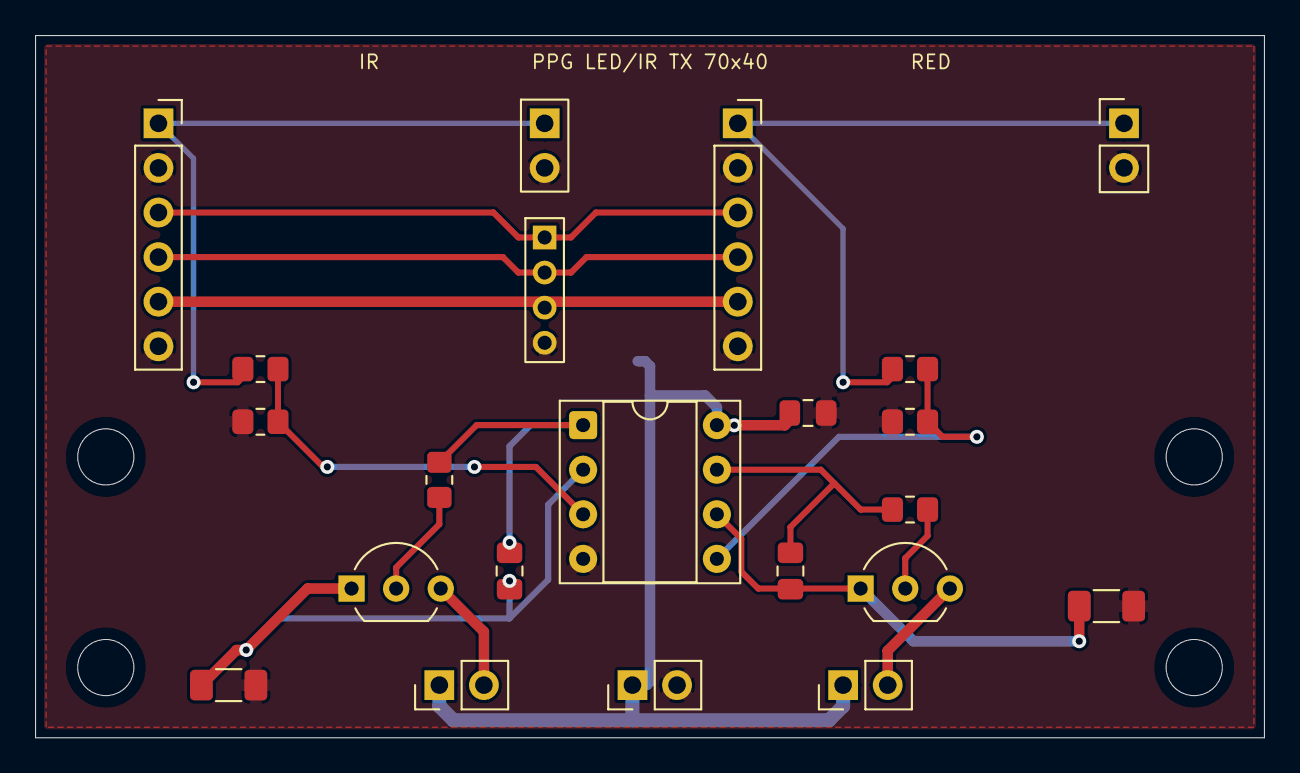
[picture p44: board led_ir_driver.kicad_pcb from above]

Board: 2 copper layers, 70.0 x 40.0 mm, 26 parts (1 on the bottom side), 17 nets.

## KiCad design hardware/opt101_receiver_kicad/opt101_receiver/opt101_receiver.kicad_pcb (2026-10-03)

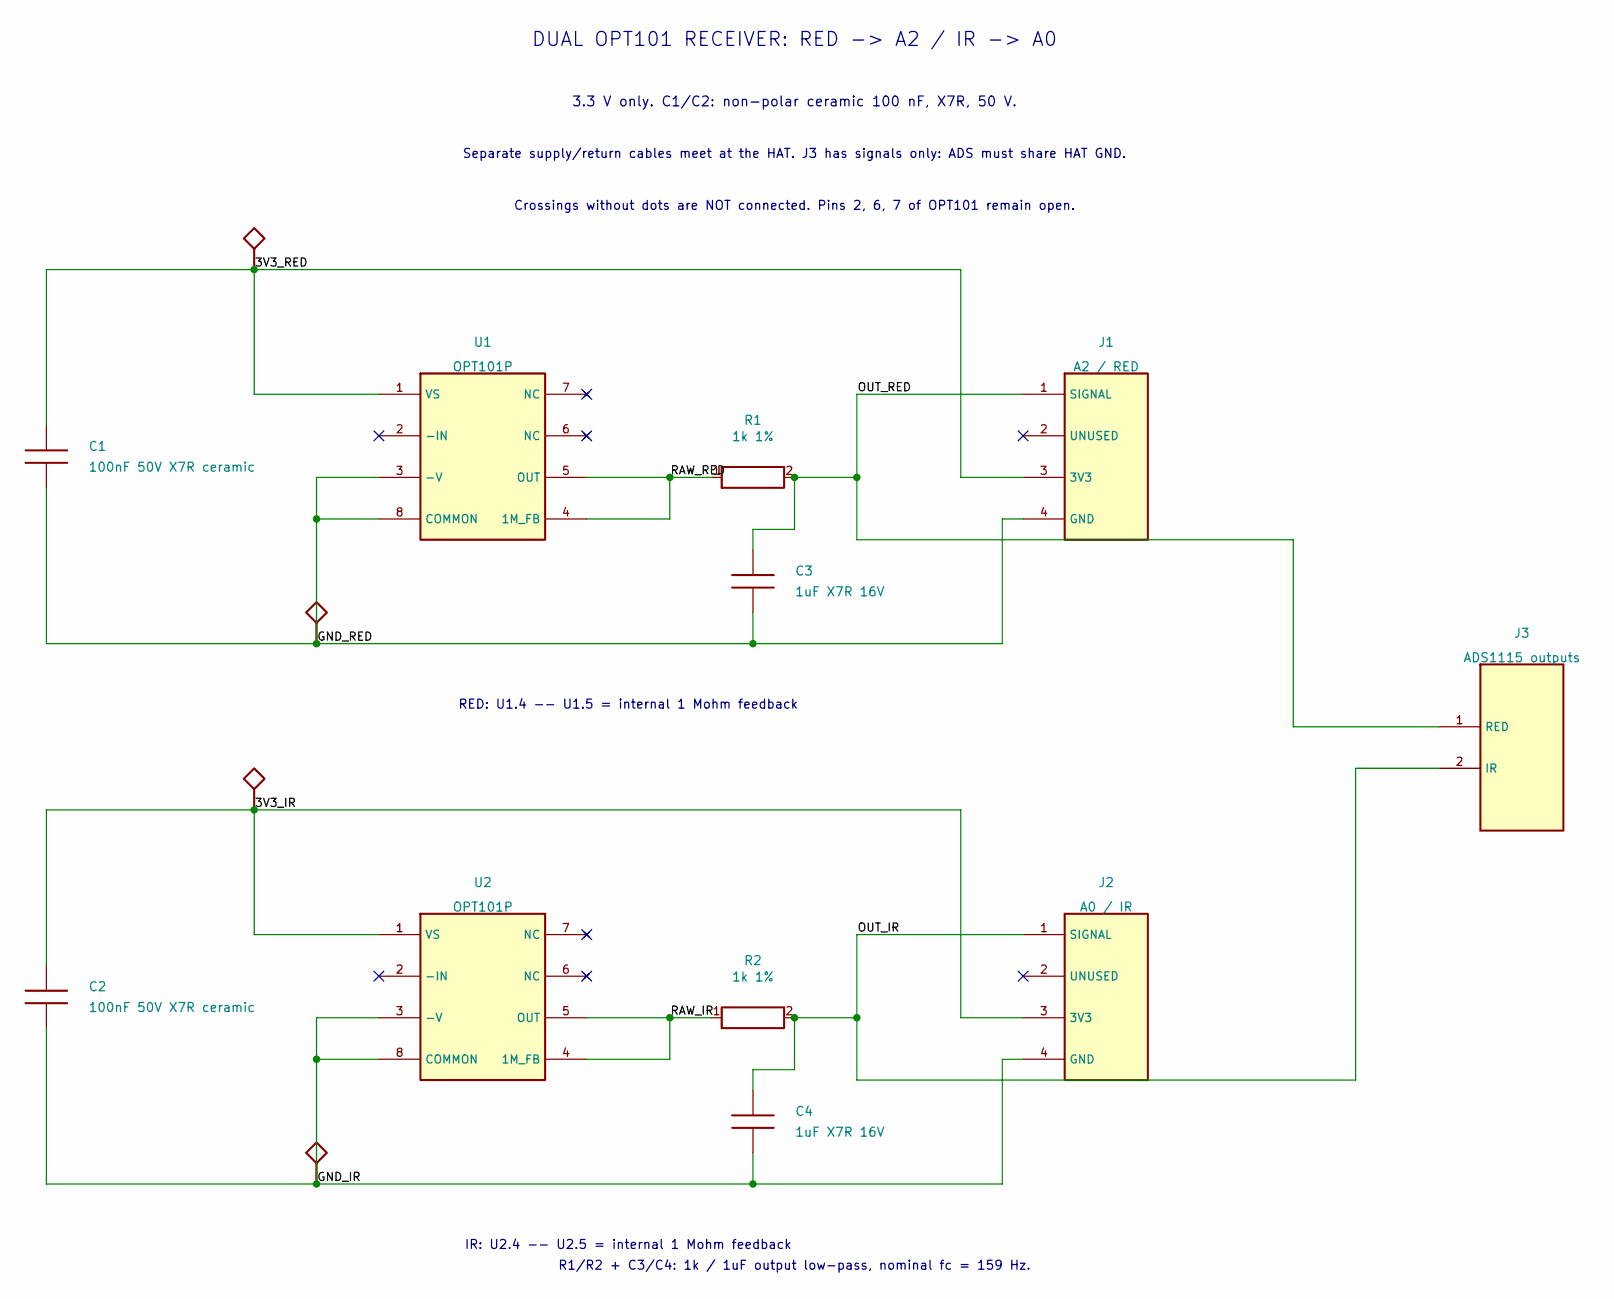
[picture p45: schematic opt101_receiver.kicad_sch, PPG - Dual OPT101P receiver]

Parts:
C1, C2: 100nF 50V X7R ceramic; C0805_Hand
C3, C4: 1uF X7R 16V; C0805_Hand
J1: A2 / RED; Header_1x04_P2mm
J2: A0 / IR; Header_1x04_P2mm
J3: ADS1115 outputs; Header_1x02_P2.54mm
R1, R2: 1k 1%; R0805_Hand
U1, U2: OPT101P; DIP8_Socket

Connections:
/3V3_IR: C2.1, J2.3 (3V3), U2.1 (VS)
/3V3_RED: C1.1, J1.3 (3V3), U1.1 (VS)
/GND_IR: C2.2, C4.2, J2.4 (GND), U2.3 (-V), U2.8 (COMMON)
/GND_RED: C1.2, C3.2, J1.4 (GND), U1.3 (-V), U1.8 (COMMON)
/OUT_IR: C4.1, J2.1 (SIGNAL), J3.2 (IR), R2.2
/OUT_RED: C3.1, J1.1 (SIGNAL), J3.1 (RED), R1.2
/RAW_IR: R2.1, U2.4 (1M_FB), U2.5 (OUT)
/RAW_RED: R1.1, U1.4 (1M_FB), U1.5 (OUT)

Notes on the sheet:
RED: U1.4 -- U1.5 = internal 1 Mohm feedback
IR: U2.4 -- U2.5 = internal 1 Mohm feedback
DUAL OPT101 RECEIVER: RED -> A2 / IR -> A0
3.3 V only. C1/C2: non-polar ceramic 100 nF, X7R, 50 V.
Separate supply/return cables meet at the HAT. J3 has signals only: ADS must share HAT GND.
Crossings without dots are NOT connected. Pins 2, 6, 7 of OPT101 remain open.
R1/R2 + C3/C4: 1k / 1uF output low-pass, nominal fc = 159 Hz.

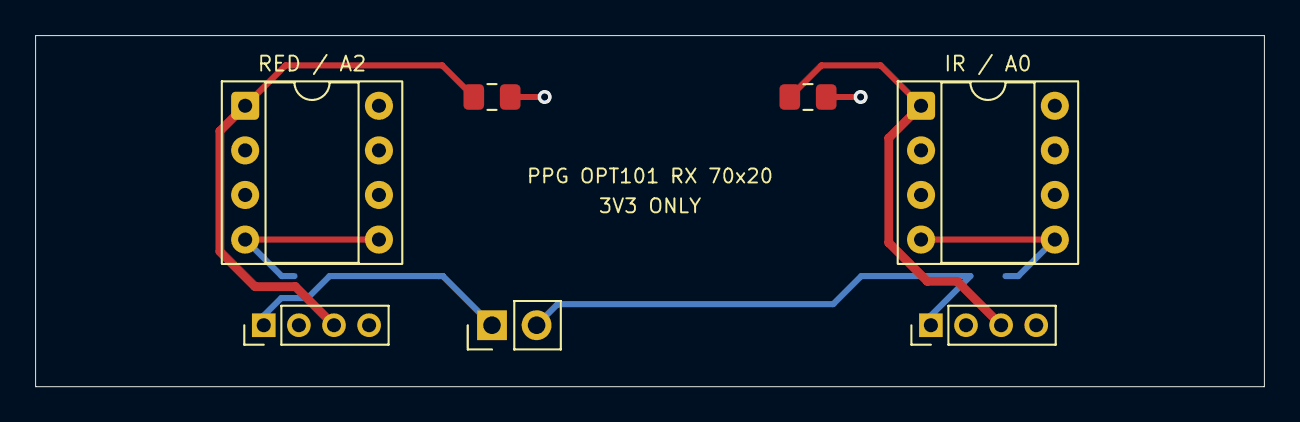
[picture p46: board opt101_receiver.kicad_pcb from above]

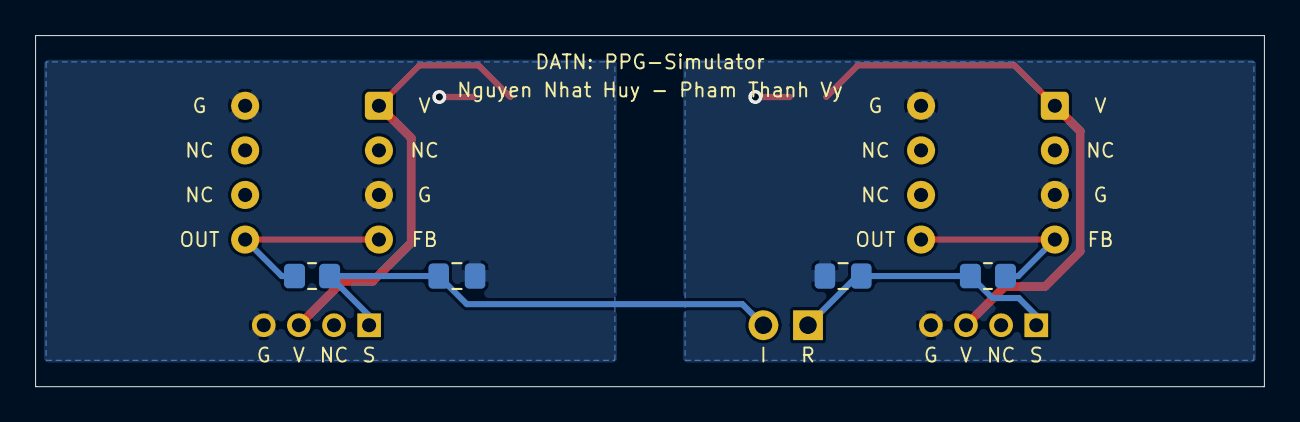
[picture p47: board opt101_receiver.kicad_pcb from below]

Board: 2 copper layers, 70.0 x 20.0 mm, 11 parts (4 on the bottom side), 8 nets.

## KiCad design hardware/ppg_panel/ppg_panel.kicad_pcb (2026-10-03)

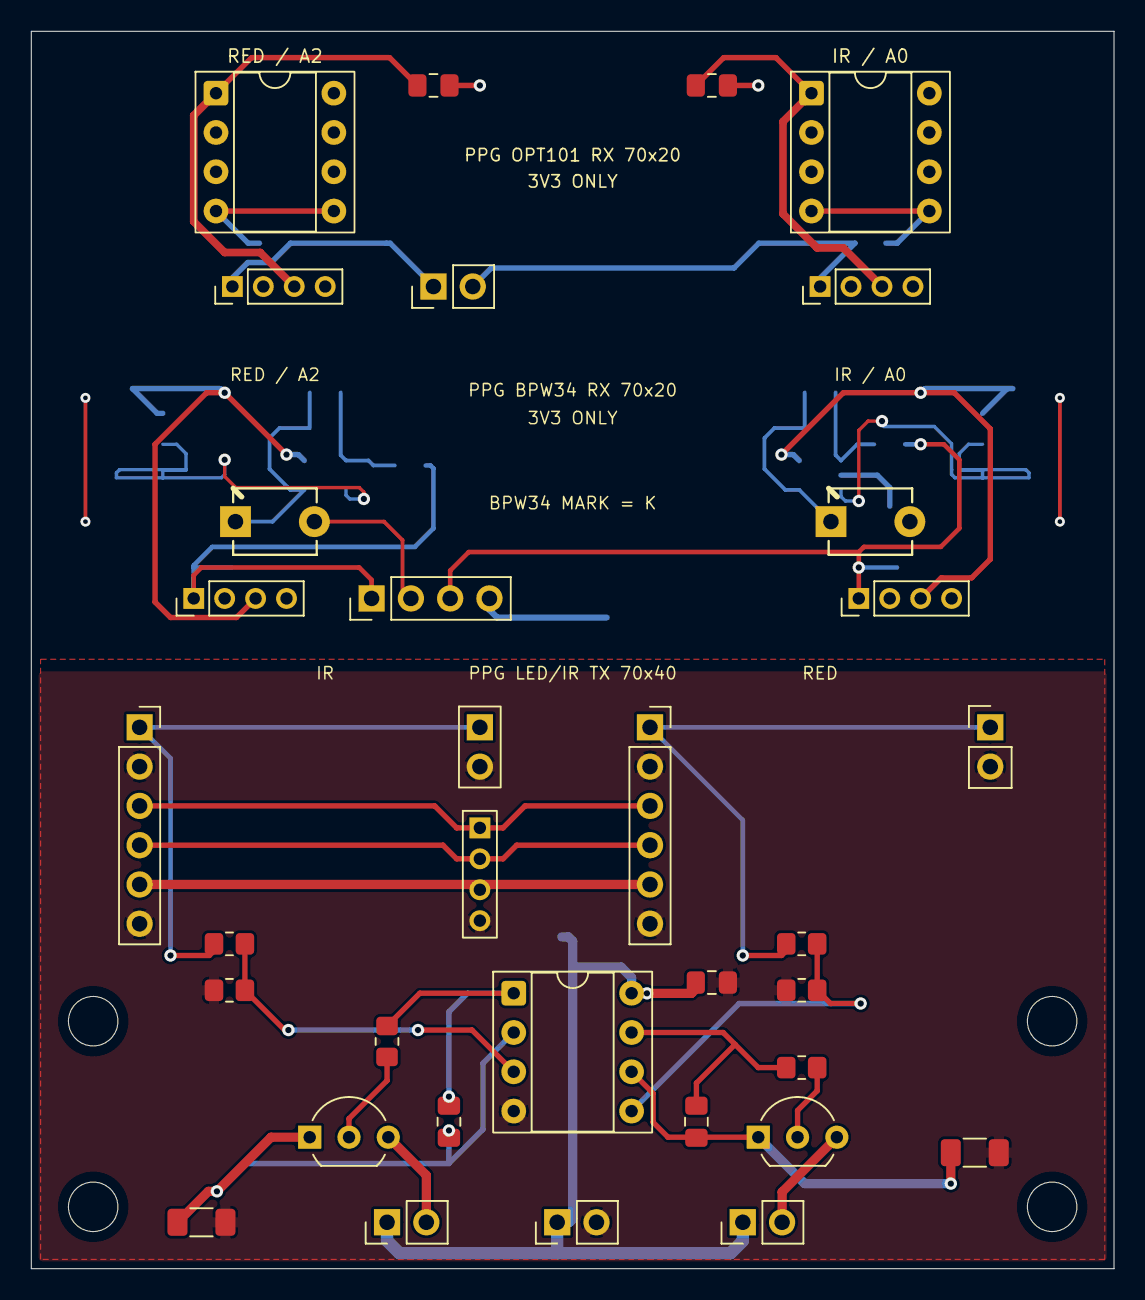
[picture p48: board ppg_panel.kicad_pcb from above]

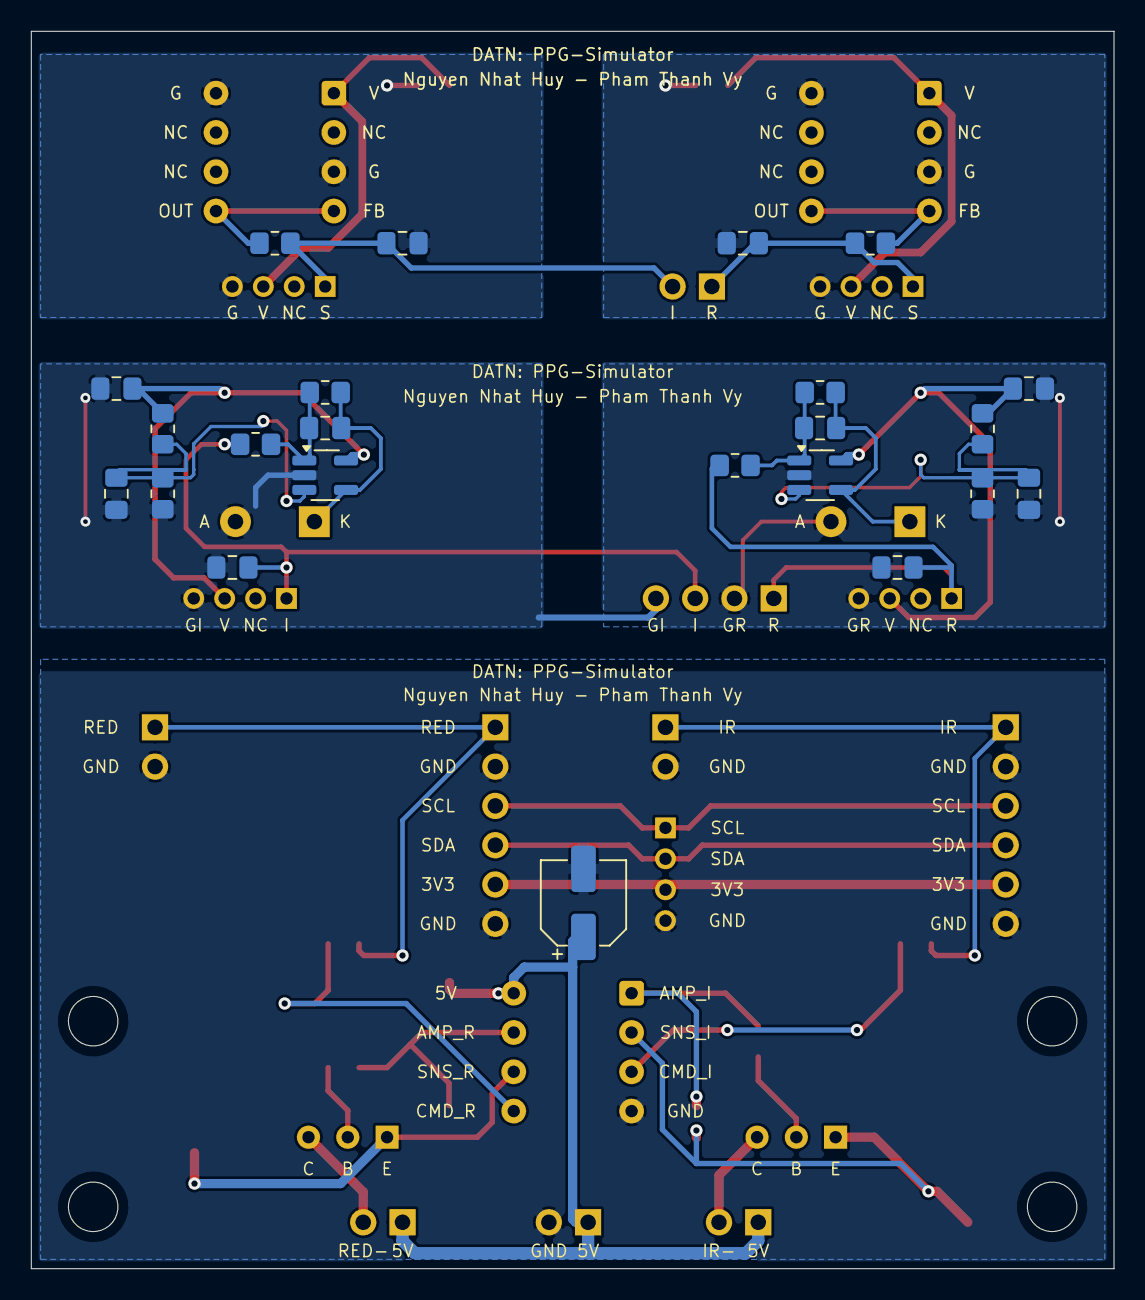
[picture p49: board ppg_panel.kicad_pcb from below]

Board: 2 copper layers, 70.0 x 80.0 mm, 60 parts (23 on the bottom side), 37 nets.

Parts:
BPW_C1, BPW_C2: 22pF C0G; C0805_Hand
BPW_C3, BPW_C4, BPW_C5, BPW_C6: 100nF X7R; C0805_Hand
BPW_C7, BPW_C8: 1uF X7R 16V; C0805_Hand
BPW_D1: BPW34 RED; BPW34_THT
BPW_D2: BPW34 IR; BPW34_THT
BPW_J1: A2 / RED; Header_1x04_P2mm
BPW_J2: A0 / IR; Header_1x04_P2mm
BPW_J3: ADS1115: RED/GND/IR/GND; Header_1x04_P2.54mm
BPW_R1, BPW_R2: 1M 1%; R0805_Hand
BPW_R3, BPW_R4: 1k 1%; R0805_Hand
BPW_R5, BPW_R6: 100k 1%; R0805_Hand
BPW_R7, BPW_R8: 10k 1%; R0805_Hand
BPW_U1, BPW_U2: OPA333AIDBVR; SOT23_5_Hand
OPT_C1, OPT_C2: 100nF 50V X7R ceramic; C0805_Hand
OPT_C3, OPT_C4: 1uF X7R 16V; C0805_Hand
OPT_J1: A2 / RED; Header_1x04_P2mm
OPT_J2: A0 / IR; Header_1x04_P2mm
OPT_J3: ADS1115 outputs; Header_1x02_P2.54mm
OPT_R1, OPT_R2: 1k 1%; R0805_Hand
OPT_U1, OPT_U2: OPT101P; DIP8_Socket
TX_C2, TX_C4: DNP loop comp; C
TX_C5: 100nF X7R 50V; C
TX_C7: 10uF 16V; CP
TX_H1, TX_H2, TX_H3, TX_H4: M3 / 3.2mm; Hole
TX_J1: MCP4725 IR 0x60; Socket6
TX_J2: PI I2C INPUT / IR OUT; HeaderMixed
TX_J3: MCP4725 RED 0x61; Socket6
TX_J4: RED DAC OUT / GND; Header2
TX_J5: IR LED A / K; Header2
TX_J6: RED LED A / K; Header2
TX_J7: 5V INPUT / GND; Header2
TX_Q1, TX_Q2: 2N4401 / E-B-C; NPN
TX_R1, TX_R2, TX_R6, TX_R7: 10k 1%; R
TX_R3, TX_R8: 1k; R
TX_R4, TX_R9: 100R 1% 0.25W; RSense
TX_U1: LM358P / DIP8 socket; DIP8

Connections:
BPW/3V3_IR: BPW_C6.1, BPW_J2.3, BPW_R6.2, BPW_U2.5
BPW/3V3_RED: BPW_C5.1, BPW_J1.3, BPW_R5.2, BPW_U1.5
BPW/FB_IR: BPW_C2.2, BPW_R2.2, BPW_R4.1, BPW_U2.1
BPW/FB_RED: BPW_C1.2, BPW_R1.2, BPW_R3.1, BPW_U1.1
BPW/GND_IR: BPW_C4.2, BPW_C6.2, BPW_C8.2, BPW_D2.2, BPW_J2.4, BPW_J3.4, BPW_R8.1, BPW_U2.2
BPW/GND_RED: BPW_C3.2, BPW_C5.2, BPW_C7.2, BPW_D1.2, BPW_J1.4, BPW_J3.2, BPW_R7.1, BPW_U1.2
BPW/OUT_IR: BPW_C8.1, BPW_J2.1, BPW_J3.3, BPW_R4.2
BPW/OUT_RED: BPW_C7.1, BPW_J1.1, BPW_J3.1, BPW_R3.2
BPW/SUM_IR: BPW_C2.1, BPW_D2.1, BPW_R2.1, BPW_U2.4
BPW/SUM_RED: BPW_C1.1, BPW_D1.1, BPW_R1.1, BPW_U1.4
BPW/VREF_IR: BPW_C4.1, BPW_R6.1, BPW_R8.2, BPW_U2.3
BPW/VREF_RED: BPW_C3.1, BPW_R5.1, BPW_R7.2, BPW_U1.3
OPT/3V3_IR: OPT_C2.1, OPT_J2.3, OPT_U2.1
OPT/3V3_RED: OPT_C1.1, OPT_J1.3, OPT_U1.1
OPT/GND_IR: OPT_C2.2, OPT_C4.2, OPT_J2.4, OPT_U2.3, OPT_U2.8
OPT/GND_RED: OPT_C1.2, OPT_C3.2, OPT_J1.4, OPT_U1.3, OPT_U1.8
OPT/OUT_IR: OPT_C4.1, OPT_J2.1, OPT_J3.2, OPT_R2.2
OPT/OUT_RED: OPT_C3.1, OPT_J1.1, OPT_J3.1, OPT_R1.2
OPT/RAW_IR: OPT_R2.1, OPT_U2.4, OPT_U2.5
OPT/RAW_RED: OPT_R1.1, OPT_U1.4, OPT_U1.5
TX/3V3: TX_J1.5, TX_J2.5, TX_J3.5
TX/5V: TX_C5.1, TX_C7.1, TX_J5.1, TX_J6.1, TX_J7.1, TX_U1.8
TX/AMP_IR: TX_C2.1, TX_R3.1, TX_U1.1
TX/AMP_RED: TX_C4.1, TX_R8.1, TX_U1.7
TX/BASE_IR: TX_Q1.2, TX_R3.2
TX/BASE_RED: TX_Q2.2, TX_R8.2
TX/CMD_IR: TX_R1.2, TX_R2.1, TX_U1.3
TX/CMD_RED: TX_R6.2, TX_R7.1, TX_U1.5
TX/DAC_IR: TX_J1.1, TX_J2.1, TX_R1.1
TX/DAC_RED: TX_J3.1, TX_J4.1, TX_R6.1
TX/GND: TX_C5.2, TX_C7.2, TX_J1.2, TX_J1.6, TX_J2.2, TX_J2.6, TX_J3.2, TX_J3.6, TX_J4.2, TX_J7.2, TX_R2.2, TX_R4.2, TX_R7.2, TX_R9.2, TX_U1.4
TX/LED_K_IR: TX_J5.2, TX_Q1.3
TX/LED_K_RED: TX_J6.2, TX_Q2.3
TX/SCL: TX_J1.3, TX_J2.3, TX_J3.3
TX/SDA: TX_J1.4, TX_J2.4, TX_J3.4
TX/SENSE_IR: TX_C2.2, TX_Q1.1, TX_R4.1, TX_U1.2
TX/SENSE_RED: TX_C4.2, TX_Q2.1, TX_R9.1, TX_U1.6

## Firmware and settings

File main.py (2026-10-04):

#!/usr/bin/env python3
"""
main.py — PPG Signal Simulator for Raspberry Pi 4 (CustomTkinter GUI)

Usage:
    python3 main.py                        # Normal mode + BLE (requires RPi hardware)
    python3 main.py --dry-run              # Dry-run + BLE (no hardware, simulated I/O)
    python3 main.py --no-ble               # Diagnostic GUI mode without BLE
    python3 main.py --dry-run --ble-only   # Headless: engine + BLE, no GUI (testing/CI)
"""

import sys
import os
import argparse
import signal
import time

# Parse --dry-run before importing config
parser = argparse.ArgumentParser(description="PPG Signal Simulator for Raspberry Pi 4")
parser.add_argument("--dry-run", action="store_true", help="Run without hardware (simulated I/O)")
parser.add_argument("--ble", action="store_true",
                    help="Deprecated compatibility flag; BLE starts by default")
parser.add_argument("--no-ble", action="store_true",
                    help="Disable the BLE GATT server (diagnostics only)")
parser.add_argument("--ble-only", action="store_true",
                    help="Headless mode: engine + BLE server, no GUI (Ctrl+C to stop)")
parser.add_argument("--page", choices=("Pathology", "Calibration", "Playback", "Neural"),
                    default="Pathology", help="Initial GUI page; output stays off")
args = parser.parse_args()

if args.dry_run:
    os.environ["PPG_DRY_RUN"] = "1"

from config import DEVICE_NAME, FIRMWARE_VERSION, FIRMWARE_DATE, DRY_RUN
from comm.logger import log
from config_store import load_config, save_config, config_from_ppg_params, apply_config_to_params
from core.signal_engine import SignalEngine
from hw.opt101_rx import OPT101Receiver
from ui.ctk_app import CTkApp


def start_ble(engine):
    """Start the BLE GATT server; returns the BleServer or None on failure."""
    try:
        from comm.ble_server import BleServer
    except ImportError as exc:
        log.error(f"BLE unavailable ({exc}) — install with: pip install -r requirements/ble.txt")
        return None
    ble = BleServer(engine)
    try:
        ble.start()
    except RuntimeError as exc:
        log.error(f"BLE unavailable: {exc}")
        return None
    return ble


def save_current_config(engine, language="en", theme="light"):
    try:
        p = engine.get_ppg_params()
        cfg = config_from_ppg_params(p)
        cfg["condition"] = p.condition
        from ui.i18n import normalise_language
        cfg["language"] = normalise_language(language)
        cfg["theme"] = theme if theme in ("light", "dark") else "light"
        save_config(cfg)
    except Exception as e:
        log.error(f"Failed to save config: {e}")


def main():
    log.info("=" * 50)
    log.info(f"  {DEVICE_NAME} v{FIRMWARE_VERSION}")
    log.info(f"  {FIRMWARE_DATE}")
    log.info(f"  Mode: {'DRY-RUN' if DRY_RUN else 'HARDWARE'}")
    log.info("=" * 50)

    engine = SignalEngine.get_instance()
    engine.begin()

    # Phase 5: OPT101 RX acquisition (Grove ADC 0x08, IR=A0 / Red=A2).
    # RX failure must not block TX/UI — the app degrades to TX-only.
    rx = OPT101Receiver.get_instance()
    if rx.begin():
        rx.start()
    else:
        log.error("RX unavailable — continuing TX-only (no OPT101 acquisition)")

    # Load config
    config = load_config()
    p = engine.get_ppg_params()
    apply_config_to_params(config, p)
    engine.load_parameters(p)

    # BLE remote control starts with every normal Pi app launch.  --no-ble is
    # retained only as a recovery/diagnostic escape hatch; --ble remains a
    # harmless compatibility flag for existing launchers.
    ble_server = None
    if not args.no_ble or args.ble_only:
        ble_server = start_ble(engine)

    # ─── Headless BLE mode: no GUI, run until interrupted ────────────────────
    if args.ble_only:
        if ble_server is None:
            rx.shutdown()
            engine.shutdown()
            sys.exit(1)
        log.info("Headless BLE mode — simulation auto-starts, press Ctrl+C to stop")
        try:
            engine.start_simulation(engine.get_ppg_params().condition)
            while True:
                time.sleep(1)
        except KeyboardInterrupt:
            log.info("Interrupted by user")
        finally:
            if ble_server is not None:
                ble_server.stop()
            save_current_config(engine, config.get("language", "en"), config.get("theme", "light"))
            rx.shutdown()
            engine.shutdown()
            log.info("Shutdown complete.")
        return

    # ─── Normal GUI mode (BLE enabled by default) ─────────────────────────────
    # Simulation will be started manually via the GUI

    # Initialize UI
    app = CTkApp(language=config.get("language", "en"), theme=config.get("theme", "light"))
    app._show_frame(args.page)

    # Do not let SIGINT/SIGTERM raise KeyboardInterrupt in the middle of a Tk
    # widget callback.  The handler only flips a Python flag; the regular 40 ms
    # UI tick then performs the same orderly shutdown as the window close button.
    def request_gui_shutdown(_signum, _frame):
        app.request_shutdown()

    signal.signal(signal.SIGINT, request_gui_shutdown)
    signal.signal(signal.SIGTERM, request_gui_shutdown)

    try:
        app.mainloop()
    except KeyboardInterrupt:
        log.info("Interrupted by user")
    finally:
        if ble_server is not None:
            ble_server.stop()
        save_current_config(engine, app.language, app.theme)
        rx.shutdown()
        engine.shutdown()
        log.info("Shutdown complete.")


if __name__ == "__main__":
    main()

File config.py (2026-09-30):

"""
config.py — Global system configuration for PPG Signal Simulator (Raspberry Pi 4)

Hardware: Raspberry Pi 4 + Grove Base Hat (ADC) + Dual MCP4725 DAC (I2C)
         + HDMI display (auto-detect resolution) + 1 push button + 1 potentiometer (5 kΩ)

Port of the ESP32-S3 config.h to Python.
"""

import os
import platform

# ============================================================================
# SYSTEM IDENTIFICATION
# ============================================================================
DEVICE_NAME = "PPG Signal Simulator"
# Single source of truth for the version. README.md must match it
# (tests/test_version_consistency.py enforces this).
FIRMWARE_VERSION = "5.0.0"
FIRMWARE_DATE = "05 September 2026"
HARDWARE_MODEL = "Raspberry Pi 4"

# ============================================================================
# DRY-RUN MODE
# When True, all hardware access is simulated (no GPIO, no I2C, no DAC).
# Useful for development on a non-RPi machine.
# ============================================================================
DRY_RUN = os.environ.get("PPG_DRY_RUN", "0") == "1"

# ============================================================================
# LOGGING CONFIGURATION
# ============================================================================
LOG_ENABLED = os.environ.get("PPG_LOG_ENABLED", "1") == "1"
LOG_FILE = "/tmp/ppg_simulator.log"
LOG_LEVEL = "DEBUG"  # DEBUG, INFO, WARNING, ERROR

# ============================================================================
# CONFIGURATION PERSISTENCE
# ============================================================================
CONFIG_JSON_PATH = os.path.join(os.path.dirname(os.path.abspath(__file__)), "config.json")

# ============================================================================
# PIN CONFIGURATION — MCP4725 DACs (I2C Bus 1)
# ============================================================================
I2C_BUS = 1             # /dev/i2c-1
DAC_ADDR_IR  = 0x60     # MCP4725 address for IR channel
DAC_ADDR_RED = 0x61     # MCP4725 address for Red channel

# ============================================================================
# PIN CONFIGURATION — GROVE BASE HAT ADC (I2C)
# ============================================================================
# The Grove Base Hat on this system uses the MM32 MCU, which answers at I2C
# address 0x08 [VERIFIED-USER; corroborated by grove_base_hat.pdf p.3: "the IIC
# address of MM32 is 0x08, while the STM32 is 0x04"]. It shares /dev/i2c-1 with
# both MCP4725 DACs at 0x60/0x61. Do NOT revert to 0x04 — that is the STM32
# revision of the same HAT, which is not the board installed here.
# Verified RX mapping [VERIFIED-USER 2026-07-12, fixed — never swap]:
#     OPT101 (IR)  -> A0  (Grove ADC channel 0)
#     OPT101 (Red) -> A2  (Grove ADC channel 2)
#     A1 is NOT used for OPT101.
# (Earlier phase docs stated A1 = Red; that mapping is stale and superseded.)
# OPT101 acquisition is implemented in Phase 5 (hw/opt101_rx.py).
GROVE_ADC_ADDR = 0x08   # Grove Base Hat MM32 ADC I2C address [VERIFIED-USER]
ADC_CHANNEL_IR = 0      # A0 — OPT101 IR photodiode channel
ADC_CHANNEL_RED = 2     # A2 — OPT101 Red photodiode channel
# GROVE_ADC_CHANNEL below is only referenced by the deprecated
# hw/adc_reader.py (legacy potentiometer input); do not use for OPT101 RX.
GROVE_ADC_CHANNEL = 0   # A0 port on Grove Base Hat (legacy adc_reader only)

# ============================================================================
# PIN CONFIGURATION — PUSH BUTTON (BCM numbering, active LOW, internal pull-up)
# ============================================================================
BTN_MODE_PIN = 17       # GPIO17 (BCM) — Mode button
BTN_DEBOUNCE_MS = 200   # Debounce interval in ms

# ============================================================================
# SIGNAL SAMPLING CONFIGURATION
# ============================================================================

# Timer master frequency (internal buffer rate)
# MCP4725 I2C can sustain ~1 kHz writes in fast mode
# Pi desktop + shared I2C may not sustain 1 kHz. Keep a validated integer
# multiple of the 100 Hz model rate; deployment can select 500 Hz explicitly.
FS_TIMER_HZ = int(os.environ.get("PPG_DAC_RATE_HZ", "500" if platform.machine() == "aarch64" else "1000"))
if FS_TIMER_HZ not in (100, 200, 500, 1000):
    raise ValueError("PPG_DAC_RATE_HZ must be 100, 200, 500 or 1000")
SAMPLE_RATE_HZ = FS_TIMER_HZ   # Alias

# PPG model generation rate
# PPG bandwidth: 0.5–10 Hz → Nyquist = 20 Hz
# Using 100 Hz for smooth waveform display
MODEL_SAMPLE_RATE_PPG = 100     # Hz

# deltaTime for model (seconds)
MODEL_DT_PPG = 1.0 / MODEL_SAMPLE_RATE_PPG  # 10 ms

# Model tick interval in microseconds
MODEL_TICK_US_PPG = 1_000_000 // MODEL_SAMPLE_RATE_PPG  # 10000 us

# Upsample ratio: interpolation from model rate to timer rate
UPSAMPLE_RATIO_PPG = FS_TIMER_HZ // MODEL_SAMPLE_RATE_PPG  # 5 on Pi; 10 at 1 kHz
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

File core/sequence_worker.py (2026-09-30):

"""Isolated CPU inference process: stdout contains exactly one JSON preview."""
from dataclasses import asdict
import json
import sys
from core.neural_preview import LSMSequenceGenerator

if __name__ == '__main__':
    preview=LSMSequenceGenerator().generate(int(sys.argv[1]))
    print(json.dumps(asdict(preview),allow_nan=False))

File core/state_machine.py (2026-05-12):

"""
state_machine.py — System state machine for PPG Signal Simulator.

Port of state_machine.cpp.
State flow: INIT → SELECT_CONDITION → SIMULATING ↔ PAUSED
"""

# ─── System States ───
STATE_INIT             = 0
STATE_SELECT_CONDITION = 1
STATE_SIMULATING       = 2
STATE_PAUSED           = 3
STATE_ERROR            = 4

# ─── System Events ───
EVT_INIT_COMPLETE     = 0
EVT_BTN_MODE_PRESS    = 1
EVT_BTN_UP_PRESS      = 2
EVT_BTN_DOWN_PRESS    = 3
EVT_SELECT_CONDITION  = 4
EVT_START_SIMULATION  = 5
EVT_PAUSE             = 6
EVT_RESUME            = 7
EVT_STOP              = 8
EVT_ERROR             = 9

# ─── UI Edit Modes ───
EDIT_CONDITION_SELECT = 0
EDIT_HR               = 1
EDIT_PI               = 2
EDIT_SPO2             = 3
EDIT_RR               = 4
EDIT_NOISE            = 5
EDIT_COUNT            = 6

_STATE_NAMES = {
    STATE_INIT: "INIT", STATE_SELECT_CONDITION: "SELECT_CONDITION",
    STATE_SIMULATING: "SIMULATING", STATE_PAUSED: "PAUSED", STATE_ERROR: "ERROR",
}

_EDIT_NAMES = {
    EDIT_CONDITION_SELECT: "Condition", EDIT_HR: "Heart Rate",
    EDIT_PI: "Perf. Index", EDIT_SPO2: "SpO2",
    EDIT_RR: "Resp. Rate", EDIT_NOISE: "Noise",
}

CONDITION_COUNT = 6


class StateMachine:
    """System state machine with edit mode cycling."""

    def __init__(self):
        self.state = STATE_INIT
        self.selected_condition = 0
        self.edit_mode = EDIT_CONDITION_SELECT
        self._on_state_change = None

    def set_state_change_callback(self, callback):
        """Set callback: callback(old_state, new_state)."""
        self._on_state_change = callback

    def process_event(self, event: int, param: int = 0):
        """Process a system event."""
        old = self.state
        new = old

        if old == STATE_INIT:
            if event == EVT_INIT_COMPLETE:
                new = STATE_SELECT_CONDITION

        elif old == STATE_SELECT_CONDITION:
            if event == EVT_SELECT_CONDITION:
                self.selected_condition = param
            elif event in (EVT_START_SIMULATION, EVT_BTN_MODE_PRESS):
                new = STATE_SIMULATING
            elif event == EVT_BTN_UP_PRESS:
                self.selected_condition = (self.selected_condition + 1) % CONDITION_COUNT
            elif event == EVT_BTN_DOWN_PRESS:
                self.selected_condition = (self.selected_condition - 1) % CONDITION_COUNT

        elif old == STATE_SIMULATING:
            if event == EVT_BTN_MODE_PRESS:
                self.edit_mode = (self.edit_mode + 1) % EDIT_COUNT
            elif event == EVT_PAUSE:
                new = STATE_PAUSED
            elif event == EVT_STOP:
                new = STATE_SELECT_CONDITION
                self.edit_mode = EDIT_CONDITION_SELECT

        elif old == STATE_PAUSED:
            if event in (EVT_RESUME, EVT_BTN_MODE_PRESS):
                new = STATE_SIMULATING
            elif event == EVT_STOP:
                new = STATE_SELECT_CONDITION
                self.edit_mode = EDIT_CONDITION_SELECT

        elif old == STATE_ERROR:
            if event == EVT_INIT_COMPLETE:
                new = STATE_SELECT_CONDITION

        if new != old:
            self.state = new
            if self._on_state_change:
                self._on_state_change(old, new)

    @staticmethod
    def state_to_string(state: int) -> str:
        return _STATE_NAMES.get(state, "UNKNOWN")

    @staticmethod
    def edit_mode_to_string(mode: int) -> str:
        return _EDIT_NAMES.get(mode, "Unknown")

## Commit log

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2026-08-29 add 3D system model: dual-lane dark chamber on shared base, LED driver board (LM358 + 2N4401 + replaceable sense resistors), offline web viewer with PPG optical simulation (Allen 2007 3-gaussian mode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
    [aperture_ir_blank.stl, aperture_ir_d2.stl, aperture_ir_d5.stl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]
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2026-08-30 review fixes: deploy script (remote tip, mktemp+trap, fail-fast), shared hood-bolt/slider constants, lid STL orientation, so luong chup/vit + 11 chi tiết
    [00_ppg_hop_toi_A1_all_in_one.stl, 01_than_hop_toi.stl, 06_chup_luon_day_trai.stl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]
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2026-09-06 fix: correct enclosure fits and complete dual-lane print kit
    [00_ban_1_co_khi.stl, 00_ban_2_khau_do_khung.stl, 00_ppg_hop_toi_A1_all_in_one.stl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]
2026-09-08 fix(cad): sync current 3D viewer and supported slide shaft geometry
    [body.stl, slide_shaft_red.stl]
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2026-09-12 feat: BLE GATT server (bless) + AC/DC 0-1500mV limits
    - comm/ble_server.py: bless BLE peripheral (service ...def0, write/notify/status)
    - Protocol: JSON delta-merge command, 50Hz waveform (DAC mV), 5Hz status,
    origin/seq echo rule for bidirectional sync
    - main.py: --ble (GUI+BLE) and --ble-only (headless) modes
    - AC/DC limits: 0-1500 mV both channels (was 0.1-300/100-3000)
    - validate_ac_dc allows DC=0 flatline; GUI reflects external (BLE) changes
    - PPG_BLE_CMD_FILE env hook; requirements/ble.txt; docs/ble_protocol.md
    - 616 tests pass, 1 skipped
    [calibration.py, config_store.py, main.py]
2026-09-16 fix: start BLE by default and scale simulator UI
    [main.py]
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2026-09-30 Verify Pi deployment and stabilize DAC timing under GUI load
    [rx_a0.csv, tx_commanded.csv]
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2026-10-03 Update README.md, hardware 45-degree routing and OPT101 diagnostic docs
    - Fix version line in README.md to ensure version consistency test passes
    - Document persistent live A0/A2 RX monitor dock and touch UI scaling
    - Document OPT101 physical bench diagnostic protocol (docs/opt101-a0-diagnostic-2026-10-01.md)
    - Detail 45-degree chamfered PCB routing, segment cleanup, and updated wiring guides
    - Update repository tree and refreshed manufacturing release ZIPs
    [bpw34_receiver-B_Cu.gbr, bpw34_receiver-B_Mask.gbr, bpw34_receiver-B_Paste.gbr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]
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2026-10-04 Redesign Classic page: side-by-side TX/RX cards and touch setpoint cards
    - Header combines brand, underlined page tabs and an outlined Setup button
    with a drawn icon; footer shows mode chip, model/DAC rates, buffer, lost
    and clipped counters, version and clock.
    - Classic page: status line that reports what the output really does
    (LEDs driven / dry run / no MCP4725 at 0x60/0x61 / DAC write errors in
    this run), Record CSV and Start/Stop actions, TX card with IR/RED lanes
    and nominal AC/DC, RX card with A0/A2 lanes, and four setpoint cards with
    -/+ steps, range or state badge and a thin touch slider.
    - RX card and the persistent dock share one status helper, so neither ever
    draws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
2026-10-04 Add navigation rail, light/dark theme, icon set and a deploy script
    - NavRail replaces the header tabs: 56 px icon column on the 1024x600
    panel that expands over the page (no plot reflow) and collapses after a
    pick or a tap outside. Theme toggle and Setup live at the bottom.
    - Light/dark theme: every surface/text token is a (light, dark) pair;
    plots stay charcoal and Tk canvases re-render on a switch. The choice is
    persisted as "theme" in config.json and normalised on load.
    - Icon set drawn with Pillow on one 24-unit grid with round caps:
    monitor, calibration target, recordings list, PPG pulse with notch,
    sliders, sun/moon, menu/collapse.
    - scripts/deploy_and_run.sh: run on the l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
    [config_store.py, main.py]
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2026-10-10 fix: subject-disjoint C2ST real-vs-real floor and runnable bundle script
    The floor probe trained and scored on windows of the same subjects with an
    unmatched domain mix, inflating the "perfect generator" AUC to ~0.81. It now
    mirrors the model C2ST layout: subject-disjoint, domain-complete halves of
    train (probe fit) and validation (scoring), averaged over repeated splits.
    On the v3 pack: mean 0.48, range 0.36-0.69 over 8 splits. Report-only value.
    prepare_physiomix_bundle.py now adds the repo root to sys.path and prints
    the v3 selection key (S_arm) instead of a missing validation_score.
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2026-10-10 feat: PhysioMix round 4 (lower LR, scale-anchored pulse, systole-preserving beat timing)
    Round-3 v2 peaked at step 2000-2500 because min-max output normalisation let the
    harmonic amplitude shrink (A1 0.3-0.5 -> 0.03-0.1 by step 10000) until the bounded
    free residual dominated; extrapolated HR then drifted (150 bpm measured as 128-136).
    PhysioMixR normalises harmonic amplitudes to a shape plus a bounded slow gain.
    Optional beat timing keeps systole fixed and lets diastole absorb IBI deviations
    (phase warping under-reported irregularity: sigma 0.2 measured 0.16, now 0.197),
    couples pulse amplitude to the preceding IBI, and allows sigma up to the label clip.
    experiment_v4 trains L1 (lr 1e-4 co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
2026-10-11 fix: scale the critic clip on lazy-R1 steps (round 6 confirmatory arm)
    Round 5 (L3 + cropped output) reached S_arm 0.527 +- 0.022 against round-3
    v2 0.596 +- 0.026, but every seed failed the d_clipped gate (~1080 clips vs
    limit 200). Measured on its final state: adversarial-step critic gradient
    norm median 2.7 (never > 10), lazy-R1 steps median 103 (always clipped), so
    R1 ran ~10x weaker than designed. r1_scaled_clip multiplies the limit on R1
    steps by the same 16-step interval; gates and decision rule are unchanged.
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2026-10-11 feat: ship PhysioMix round 6 (scale-anchored pulse, beat timing, cropped output)
    Round-6 arm L3_rel_beat_lr_crop_r1 seed 2026 (best step 8000, S_arm 0.548)
    replaces round-3 physiomix_v2. Frozen rule: mean S_arm 0.570 +- 0.023 vs
    0.596 +- 0.026 (gap 0.026 > pooled SD 0.025), S_real 0.357 vs 0.366, all
    gates on all seeds. Re-used GXU test Q 0.231 +- 0.037 vs 0.261 (report only).
    Kaggle export matched the rebuilt EMA checkpoint and was re-traced locally.
    Verified on the laptop in DRY RUN: pytest 803 passed, 10 skipped;
    smoke_physiomix_ui PASS (72/62/120/170 bpm measured 71.8/61.9/119.3/170.3;
    AF 95 bpm single window 86, median 94.3 over 20 seeds); smoke_neural_ui PASS.
    Not measured on the Pi,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
2026-10-11 fix: stage experiment_v5 for round 7 and refuse kernels missing their entry module
    The first round-7 push failed on Kaggle with ModuleNotFoundError because the
    physio7 mode was left out of the experiment_v5 source list. stage() now checks
    every ml.* module the entry imports is in the payload; a test covers each mode.
2026-10-11 feat: ship PhysioMix round 7 (lazy-R1 weight 0.1)
    Round-7 arm L3_rel_beat_lr_crop_r1w seed 42 (best step 6500, S_arm 0.458)
    replaces round-6 L3_rel_beat_lr_crop_r1. Frozen rule: mean S_arm
    0.510 +- 0.053 vs 0.570 +- 0.023 (gap 0.059 > pooled SD 0.041), S_real
    0.360 vs 0.357 (within +0.05), all gates on all seeds. Derivative C2ST AUC
    0.753 vs 0.896; re-used GXU test Q 0.215 +- 0.012 vs 0.231 (report only).
    Verified on the laptop in DRY RUN: pytest 809 passed, 10 skipped;
    smoke_physiomix_ui PASS (72/62/95 AF/120/170 bpm measured
    71.7/61.7/93.1/118.9/170.4); smoke_neural_ui PASS.
    Not measured on the Pi, DAC or OPT101.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
2026-10-11 feat: round-8 arm with a periodic motion component, judged on wrist coverage
    Round-7 wrist windows are spectrally spread (median spectral entropy 0.82,
    ACF peak 0.24) where real wrist-exercise windows are concentrated (0.72,
    0.52), and wrist coverage on unseen people fell 40% -> 18%. PhysioMixR
    gains an optional additive motion oscillator (0.5-3.5 Hz cadence, three
    harmonics, amplitude up to 1.5x the pulse, set per condition and noise,
    starting near off). experiment_v5 variant crop_r1w_motion ships only on a
    validation wrist-Q gain beyond the pooled seed SD with S_arm within the
    incumbent's pooled SD and S_real within +0.05; stage_kernel mode physio8
    mounts round 7 as the incumbent.
    Co-Auth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
2026-10-11 feat: show the received OPT101 pulse rate on the RX lanes
    Each live RX lane header now shows "Nhịp RX NN bpm" (EN "RX rate") computed
    from the received samples only: newest gap-free stretch (>= 5 s, holes
    > 0.1 s split it), resampled to 50 Hz, moving-average band-pass, then an
    autocorrelation period that must repeat at twice its lag and agree within
    15% with the count of prominent pulses. Otherwise the lane says why there is
    no rate (too short, ADC clipping, weak swing, no clear regular rhythm).
    Dry-run and disabled channels show no rate. Pure Python (the Pi runtime has
    no numpy), recomputed at most once a second per channel, ~3 ms per estimate
    on the x86 laptop.
    Verified on synthetic RX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
2026-10-11 feat: ship PhysioMix round 9 (motion component + per-domain distribution loss)
    Round-9 arm L3_rel_beat_lr_crop_r1w_motion_dom seed 123 (best step 3500,
    S_arm 0.503) replaces round-7 L3_rel_beat_lr_crop_r1w. Frozen wrist rule:
    validation wrist Q 0.527 +- 0.060 vs 0.653 +- 0.059 (gap 0.126 > pooled SD
    0.059), mean S_arm 0.530 +- 0.029 within the incumbent's 0.510 + pooled SD
    0.043, S_real 0.344 vs 0.360, all gates on all seeds. Re-used GXU test Q
    0.194 +- 0.034 vs 0.215 (report only). The learned motion amplitude stays
    small (median 2.6% of the pulse for wrist, <= 0.8% elsewhere): the wrist
    gain comes mainly from the per-domain spectral/ACF loss.
    Verified on the laptop in DRY RUN: pytest 820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
2026-10-11 feat: score the app's LSM-GAN in the realism report, plus a 0.9-5 Hz fairness view
    realism.py --lsm adds the TorchScript LSM-GAN as source lsm_gan (unconditional,
    prompts ignored, output put through the same v3 view). --narrow-view rescores
    real and generated windows in LSM-GAN's own 0.9-5 Hz training view (state
    tests skipped); --datasets limits the datasets.
    Laptop CPU runs: ml/runs/realism-v1/realism_lsm.json (v3 view) and
    realism_lsm_narrow.json; round 9 numbers reproduce realism_round9.json.
2026-10-11 feat: PhysioFlow round 10, a rhythm-scaffold conditional flow-matching generator
    New generator family (ml/kaggle_multidomain/flow.py): systolic peak times are
    constructed from the commanded rate and IBI irregularity (as in PhysioMix) and
    given as a beat-phase scaffold to a 6.9M-parameter 1D U-Net trained with
    rectified flow matching on real v3 windows aligned to their own detected peaks.
    No critic, no circular output filter; classifier-free guidance; fixed-step Heun
    sampler inside the module, so it traces to TorchScript with the PhysioMix
    (z, condition) interface.
    experiment_flow.py: seed-42 pilot over two arms (plain, + x0 first-difference
    loss) x four samplers, then a three-seed final aga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
2026-10-11 feat: app slot for a PhysioFlow generator next to PhysioMix
    The Neural page lists "PhysioFlow · flow matching" when the bundle has a
    physioflow entry; it shares PhysioMix's worker contract (domain + target HR),
    condition schema and real reference strips. PhysioMixGenerator takes a slot
    ('physiomix' | 'physioflow'), sequence_worker accepts --model physioflow,
    prepare_physiomix_bundle.py --slot physioflow rebuilds a flow checkpoint from
    source and checks its Kaggle export with a looser tolerance (many integration
    steps). smoke_physiomix_ui.py --mode PhysioFlow runs the same UI checks.
    No PhysioFlow bundle is shipped yet, so the app is unchanged until one is.
    Tests: model/app files 67 passed;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
2026-10-11 feat: PhysioFlow loop 2, rate-flag scaffold and scripted TorchScript export
    Pilot 1 (seed 42, 16k steps, validation): best S_arm 0.610 (F1, 16 Heun
    steps) against round 9's 0.50-0.56. GXU and PERform Large matched or beat
    round 9 and the derivative C2ST AUC fell to 0.75-0.78 (round 9: 0.80-0.84),
    but wrist Q was 1.0-1.5 (round 9: 0.49-0.60). Cause: 87% of wrist training
    windows have a masked rate label and so no scaffold, while sampling always
    imposed one. The difference-loss arm (F2) learned much faster (S_real 0.40
    vs 0.53) but its control at 140-180 bpm drifted (MAE 1.4 -> 4.3 bpm).
    Guidance 1.5 lost on every arm. The run then died while tracing 16-step
    samplers on both workers (the trace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
2026-10-12 feat: PhysioFlow loop 3, small-t flow times and a stop-and-filter finish
    Pilot 2 (seed 42, 20k steps, validation): F3 (rate-flag scaffold, difference
    loss 1, 16 Heun steps) reached S_arm 0.537 vs round 9's 0.503-0.561, with
    derivative C2ST AUC 0.70 (round 9: 0.80-0.84) and GXU Q 0.14 (0.17-0.20).
    The remaining gap is almost all log-PSD MMD (wrist 0.53 vs 0.09).
    A local probe on the pilot-2 checkpoint (validation pools, n=128) showed the
    log-PSD term swings with the last sampling steps: a finer end grid made it
    much worse (GXU 0.075 -> 1.04), stopping at t=0.04 and applying the data view
    on a reflection-padded window improved wrist (0.53 -> 0.21) and AF/non-AF.
    A train-fitted noise floor mad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
2026-10-12 feat: bundle a trained flow arm with a chosen sampler (--sampler)
    A pilot trains one arm and scores several samplers on the same weights; its
    Kaggle export holds whichever sampler was scored last, so with --sampler the
    weights are rebuilt under that sampler's config and the export comparison is
    skipped (the manifest records the sampler and no export checksum). Used to
    preview the loop-2 checkpoint in the app on the laptop (DRY RUN smoke PASS:
    72/62/120/170 bpm measured 72.3/61.8/119.8/170.2); that preview is not committed.
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2026-10-12 fix: Neural page rate readout locked onto two beats for irregular (AF) strips
    The displayed "measured" rate took the autocorrelation peak first. On
    irregular rhythms that peak can sit at two beats, so 95 bpm AF strips were
    shown as 46-53 bpm (PhysioFlow) while the waveform had ~95 bpm. On synthetic
    AF-like strips (sigma 0.22, amplitude jitter) 250 of 600 readouts were off by
    more than 12%.
    When the autocorrelation rate is a half or third of the peak-span rate and
    the peak intervals do not alternate short/long (a dicrotic wave doubles the
    peak count with alternating intervals), the peak-span rate is shown. Regular
    and reflected-wave strips keep the autocorrelation path (existing tests).
    New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
2026-10-12 feat: ship PhysioFlow as a research mode next to PhysioMix
    Round-10 decision (rule frozen before training, validation only, 3 seeds):
    PhysioFlow S_arm 0.482 +- 0.015 vs PhysioMix round 9 0.530 +- 0.029 (gap
    0.048 > pooled SD 0.023), S_real 0.368 vs 0.344 (within +0.05), every seed
    eligible; wrist Q 0.793 vs 0.527 (allowed +0.074) failed, so PhysioMix stays
    the app model. PhysioFlow seed 42 (lowest S_arm 0.472, step 8000, 16 Heun
    steps) is bundled as the selectable "PhysioFlow · flow matching" mode.
    Seed 123 was scored on the Kaggle T4 inside the final; the final's worker
    pool then died, and seeds 42 and 2026 were scored on the laptop CPU with the
    same code (--resume-from), recorded in the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
2026-10-12 feat: PhysioFlow loop 5 (wrist): stop-band log-PSD loss, go limits, two-worker final
    Wrist diagnosis on the bundled seed-42 checkpoint: 75% of the wrist log-PSD MMD is a
    12-20 Hz residual that builds along the sampling trajectory (exposure bias), not in
    one-step denoising. Laptop fine-tune probes: full-band log-PSD loss and input
    perturbation made wrist worse; the stop-band loss helped a little. Pilot arms F7/F8
    (stop-band loss weight 1 and 3); go limits for a 3-seed final are fixed before the
    pilot (wrist Q <= 0.601, S_arm <= 0.487). The final runs at most two seeds at a time.
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2026-10-13 feat: stage loop-7 kernels on another Kaggle account from its own private datasets
    stage_kernel --owner swaps the loop-7 kernel id and mounts that account's copies of the v3 data pack and of
    round 9's decision (stage_datasets / --datasets) instead of charlesday2612's private kernels. Entry and sources
    are unchanged. Full suite: 869 passed, 10 skipped.
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2026-10-14 perf: faster UI — no forced CustomTkinter layout flushes, reused Signal setup window, no redundant redraws
    - CTkScrollbar/CTkOptionMenu redraws no longer force a whole-window
    update_idletasks (ui/ctk_perf.py, installed with the theme).
    - Signal setup window is built once and hidden on close; tabs are built on
    first show; fields reload from the engine on every open.
    - LaneView skips identical updates; TouchSlider and setpoint badges push
    only changed state to the widgets.
    Dry-run on the x86 laptop: Signal setup open 1.36-1.53 s -> 0.69 s first,
    0.04 s after; monitor-page Tk thread CPU 7.5% -> 4.2%. Not measured on the Pi.
    Full suite 894 passed, 10 skipped.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
2026-10-14 docs: step C result and client presentation page
    PaPaGei-S, a frozen PPG foundation model never trained on this project,
    ranks the generators almost exactly as the project's C2ST CNN (Spearman
    0.88 over 22 source x dataset pairs). On the GalaxyPPG test people, the
    app PhysioMix is caught mainly in the 5-8 Hz band (1% indistinguishable
    there, 52-80% at 0.5-5 Hz).
    New page docs/model-report/trinh-bay.html walks through:
    - the app's PhysioMix forward pass, stage by stage, replayed from the
    shipped checkpoint and asserted equal to its forward;
    - PhysioFlow denoising from noise to waveform (interactive and MP4);
    - the GAN critic's real/fake scores at the end of training (AUC 0.44);
    - the three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
2026-10-17 docs: step-E result (PhysioFlow wrist_daily does not replace PhysioMix round 9 by RULE_E)
    Kaggle halovie2412/ppg-galaxy-e-v1 (2 x T4, 6.6 h; staged source hashes match 0e07810a,
    FROZEN_E rule identical to the committed RULE_E). DECISION_E: ship false.
    - Original validation (seed means): S_arm 0.440 <= 0.559, wrist-exercise Q 0.585 <= 0.587
    (seed 123 alone 0.684); every seed eligible.
    - 6 everyday-wrist validation people, 5 halvings: 25.6% vs app 0.05%; gap 25.6 below the
    margin 32.5 (2 x mean per-seed halving SD 16.3; seed SD 1.2). Q 0.37 < 0.89, rate 0.99
    vs 1.16 bpm.
    - 12 GalaxyPPG test people, report only: 33.0% vs app 0.4%, Q 0.21 vs 0.88.
    assets/neural unchanged. Evidence docs/phy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
2026-10-17 test: finalize Tk garbage on the main thread between tests
    test_waveform_output::test_finite_playback_parks_outputs_and_classic_restart_clears_source
    failed only in full-suite runs with "Output worker did not stop; refusing a
    second writer".
    Cause: CustomTkinter widgets sit in reference cycles and own objects whose
    __del__ calls Tcl (CTkFont via tkinter.font.Font, tkinter.Variable). The UI
    tests leave hundreds of them in cyclic garbage (test_ui_performance alone
    >200). The next full collection runs on whichever thread allocates; when that
    is a SignalEngine worker and no Tk mainloop runs, _tkinter's WaitForMainloop
    waits ~1 s per object before raising (Font swallows the error silently), so
    t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
2026-10-18 fix: finalize destroyed Tk widgets on the Tk thread, not on output workers
    Re-showing Recordings destroys the previous list rows and leaves CTkFont and
    PhotoImage objects in reference cycles. When the automatic collector then
    runs on SignalDAC, each Tcl finalizer is marshalled to the Tk thread and
    waits with no timeout. Measured on the laptop with the real CTkApp and a
    collection forced inside SignalDAC: a 1.41 s DAC gap while a Tk callback
    was busy for 1.4 s, and Stop pressed during the collection failed after
    2.00 s with "Output worker did not stop; refusing a second writer".
    CTkApp now binds <Destroy> on the "all" tag and queues one gc.collect() at
    the next idle point on the Tk thread. T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
2026-10-18 docs: GalaxyPPG test and steps A–E in the technical model report
    chi-tiet.html had nothing on the fresh GalaxyPPG test or steps B–E; those
    results were only on index.html and trinh-bay.html. New section 9 covers the
    data and person splits, the three rule metrics (C2ST indistinguishability, Q,
    median rate error), and one table per step: A (app models on 24 new
    people), B (retrain with 12 GalaxyPPG people), B-LSM, C (PaPaGei and the
    band/physiology judges), D (wrist_daily domain) and E (6 validation people,
    3 seeds, ship false: 25.6 < 32.5). Later sections are renumbered 10–12.
    Every number was checked by script against the evidence JSON files (141
    values). Two rounding slips copied fro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
2026-10-18 docs: fix stale references in the Pi setup notes and the print guide
    - hw/opt101_rx.py:161 and config.py:60 are now lines 172 and 63.
    - The gpiozero note claimed grep finds nothing; it finds the
    forbidden-import lists in two scripts and one test.
    - docs/system_3d/README.md still pointed to print_bambu/ and
    print_bambu_v4.zip, replaced in 73b476c3 by the three-plate 180 mm
    package. Tables now follow out/print_bambu_180/manifest.json and the
    plate STL bounding boxes.
2026-10-18 feat: start the simulator with the Pi desktop session, restart it after a crash
    The app ran only from the desktop icon or from deploy_and_run.sh's
    transient unit; nothing started it after a reboot or after a crash.
    - packaging/linux/ppg-simulator.service.in: systemd user unit, WantedBy,
    After, PartOf and Requisite graphical-session.target. On Ubuntu 24.04
    GNOME that target is reached after GNOME Shell has exported DISPLAY,
    and gnome-session-shutdown.target stops it at logout. Restart=on-failure
    after 5 s, at most 5 starts in 300 s. KillSignal=SIGTERM takes main.py's
    shutdown path, which parks both DACs at 0 V. TimeoutStopSec=30; the
    path's own join/wait timeouts add up to 18 s.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
2026-10-19 fix: park both DACs at 0 V after every exit of the user service
    An MCP4725 holds its last code. After a crash (a signal or a non-zero exit)
    nothing parked the IR (0x60) and Red (0x61) DACs until the restarted app
    re-initialised them, and never once the start limit tripped.
    scripts/park_dacs.py opens both DACs through DACManager.begin(), which
    writes DAC_IDLE_VALUE, and logs the result with systemd's SERVICE_RESULT,
    EXIT_CODE and EXIT_STATUS. It exits 0 with PPG_DRY_RUN=1/--dry-run or when
    the DACs do not answer, and 1 when a write fails or the park passes 3 s
    (SIGALRM), well inside Ubuntu's 5 s user-manager stop cap. The unit runs it
    as ExecStopPost=- so a failed park never fails the unit o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
2026-10-19 feat: enforce one simulator instance per user inside main.py
    Two copies fight over the MCP4725 DACs on I2C and over the BLE GATT server.
    The launcher's flock and the pkill sweeps missed a copy started by hand
    with a relative path.
    - instance_lock.py: main.py takes an exclusive flock on the launcher's
    existing lock file ($XDG_STATE_HOME/ppg-simulator/app.lock) right after
    argument parsing, before any hardware, BLE or config module loads, in
    every mode. A conflict prints the holder's PID and exits 75.
    - The launcher passes its locked fd 9 through PPG_APP_LOCK_FD; Python locks
    that open file description instead of opening the file again, which would
    conflict with the launcher's own l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

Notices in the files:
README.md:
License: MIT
